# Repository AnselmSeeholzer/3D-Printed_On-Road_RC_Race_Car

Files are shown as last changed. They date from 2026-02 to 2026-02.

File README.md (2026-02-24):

# 3D-Printed On-Road RC Race Car

Videos can be found here:
[Video1](https://youtu.be/ogYVA5u91Qc?si=TGJ7EXKurzWOe1Sa)
[Video2](https://youtu.be/yxx4tnBufh8?si=RkOAHaVWVVsFRw-e)
[Video3](https://youtu.be/c6_NunxIvkY?si=fuwjfYf_-NPKvzkU)

With this 3d-printable RC-car I took part in the 2025 *Instructables Autodesk Make it Move Engeneering Student Contest* and the RC-car has won the *3D Printing Judge`s Price*.  

Detailed building instructions with a complete .f3z-file can be found on the [Instructables](https://www.instructables.com/3D-Printed-On-Road-RC-Race-Car/) website. The Instructable (without pictures and .f3z-file) was also transferred in this repository with printable .3mf-files.  

Some additional information about e.g. the suspension layout, BoM can be found in /some_information_about_the_rccar/
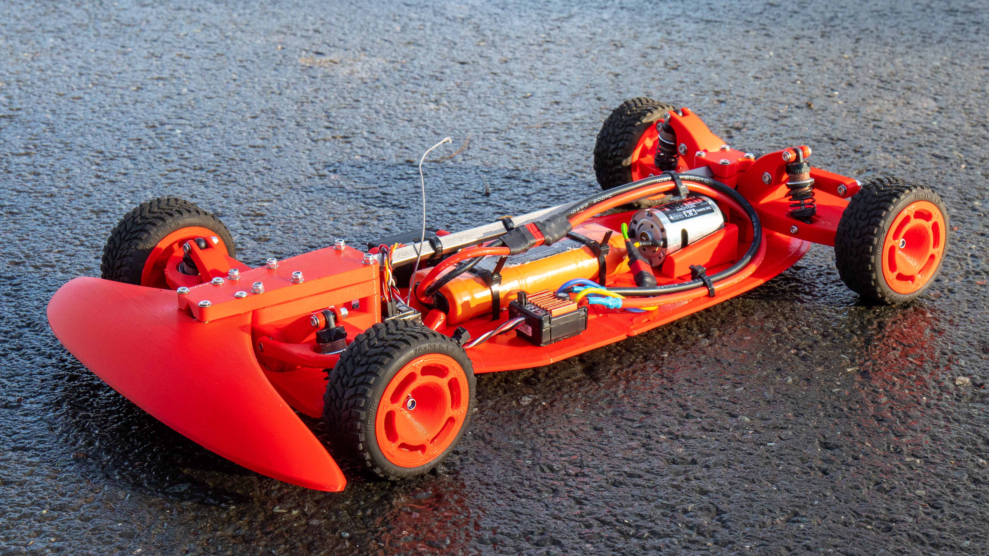
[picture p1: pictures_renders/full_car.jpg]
full_car_photo
  
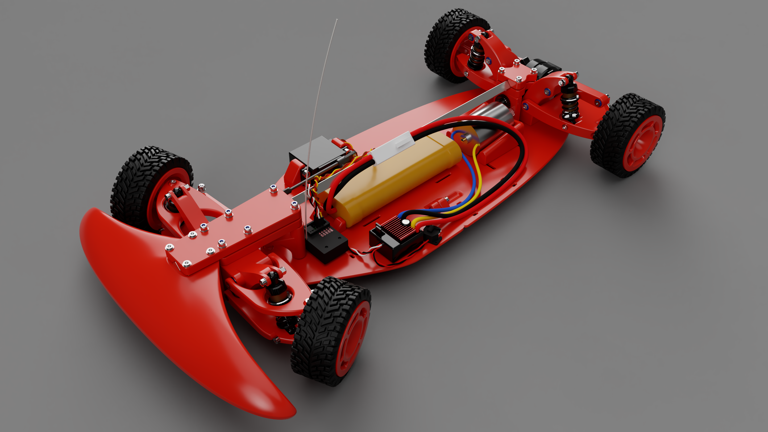
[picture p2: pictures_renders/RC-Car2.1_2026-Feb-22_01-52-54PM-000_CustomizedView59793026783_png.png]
full_car_render
  
full_car_render  
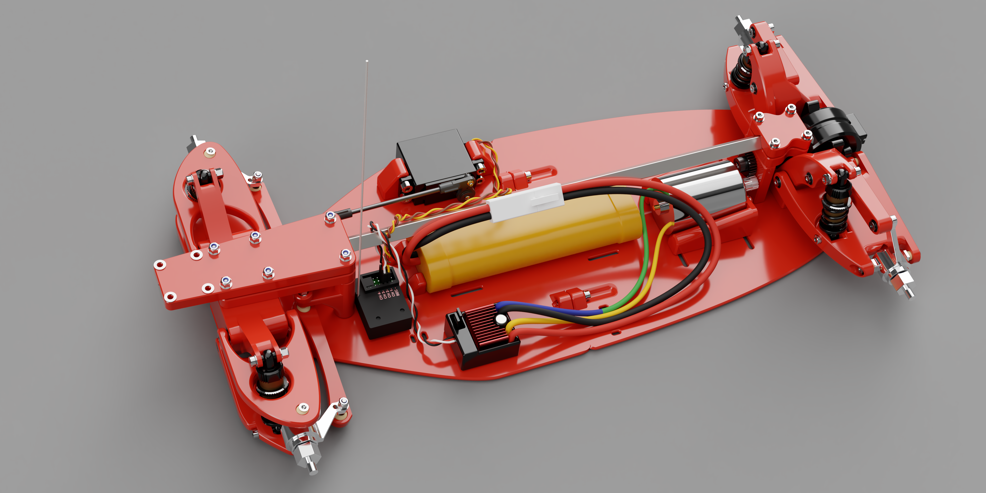
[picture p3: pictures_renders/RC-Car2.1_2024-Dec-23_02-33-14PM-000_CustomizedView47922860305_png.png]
full_car_render
  
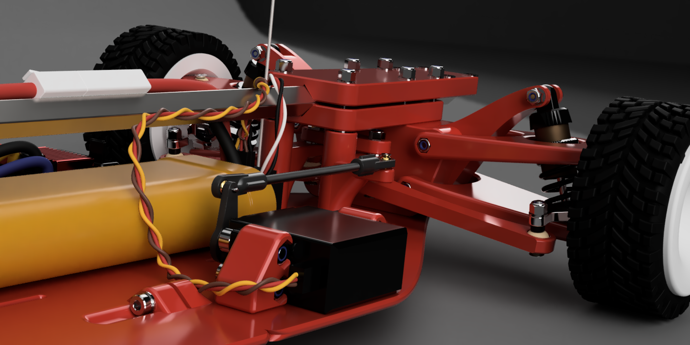
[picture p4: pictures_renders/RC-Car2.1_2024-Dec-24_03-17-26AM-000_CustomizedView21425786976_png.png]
full_car_render
  
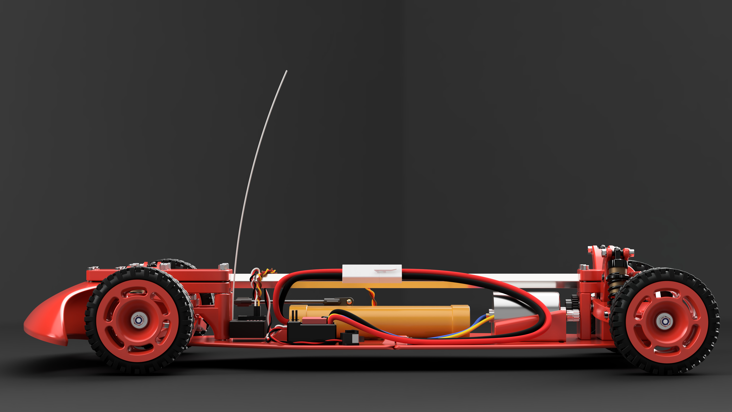
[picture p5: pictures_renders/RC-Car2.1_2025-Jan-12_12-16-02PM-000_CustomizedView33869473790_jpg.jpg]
full_car_render
  

---

## Introduction

This project showcases a 3D-printed RC race car that I designed and refined over the course of 18 months. As a physics student with a passion for vehicle dynamics, I wanted to combine my love for cars with hands-on learning. Inspired by YouTube creators like XF Motorsports, Indeterminate Design and the book Tune to Win by Carroll Smith, this project allowed me to explore the fascinating and complex field of vehicle dynamics.

The idea behind this project was not just to create an RC car, but to design one that reflects core principles of performance and handling. Through this process, I learned how concepts like weight distribution, suspension geometry, and grip dynamics work together to affect a vehicle's behavior. This Instructable is a step-by-step guide to building your own RC car, while also offering insights into the design decisions.

While designing and printing an RC car might seem challenging, I've optimized most parts to be straightforward to print -- even on a less-than-perfectly calibrated 3D printer. All holes for every bolt, nut, bearing and every tolerance are designed parametrically, so every feature's size can be easily adjusted to your likings in Autodesk Fusion. To determine if the parameters need to be changed, I have designed two test objects which use less than 10 g of filament to print.

---

## Project Goals

The main goals and conditions for this RC car were:

- **On-Road Focus**
  This car is purpose-built for smooth, on-road surfaces. Off-road capabilities were intentionally not prioritized.

- **Responsive and Predictable Handling**
  The car should feel intuitive and smooth to drive, allowing the driver to push it to its limits. Oversteer and understeer should be intentionally controllable, making it possible to explore the edge of grip and maintain a challenging driving experience.

- **Rear-Wheel Drive with Differential**
  A rear-wheel-drive setup was chosen for simplicity and driving fun. A differential ensures that the rear wheels rotate at different speeds during cornering, minimizing unwanted slip.

- **Optimized Weight Distribution**
  All heavy components are placed close to the car's center to reduce rotational inertia.

- **Efficient Suspension Design**
  The suspension is designed to maximize the contact area between the tires and the ground in all conditions (cornering, bumps, etc.), which increases grip. Internal friction at linkage points is minimized by using ball bearings or spherical bearings, enhancing the suspension's efficiency.

- **Ease of Maintenance**
  The car's design ensures that components are easily accessible for servicing and replacing parts.

---

## Why I Built This Project

I've always been fascinated by all kind of vehicles on wheels like stunt scooters, mountain bikes and more recently race cars. The physics involved in driving dynamics and car design offer a unique mix of theory and practical application. My interest deepened after watching DIY race car projects on YouTube and reading Tune to Win, which provides a great introduction to vehicle dynamics.

As a physics student, I already had a good understanding of basic physical concepts like force, torque, inertia and momentum. However, vehicle dynamics is a nuanced and complex field, and I wanted to expand my knowledge through hands-on experimentation. Designing this RC car from scratch was the perfect way to bridge theory and practice.

---

## Design Principles

The design process was guided by key engineering principles to ensure the car performs well on the track. Here are some highlights:

- **Suspension Geometry**
  The suspension layout takes into account critical factors like camber, bumpsteer, caster angle, and roll center position.

- **Ackermann Steering**
  The steering geometry approximates Ackermann principles, ensuring the wheels turn at the correct angles for smooth cornering.

- **Bump Steer Mitigation**
  The steering system is designed to minimize bump steer, which could cause unpredictable handling when the suspension compresses.

I measured different geometry layouts in Autodesk Fusion by using 2D sketches. This Data was put into spreadsheets to analyze the suspension geometry and simulate different scenarios (e.g., cornering, bumps). The tables and graphs of the final layout are attached to this Instructable for anyone interested in the technical details. For those who are interested I go into more detail of some design choices in the last chapter of this Instructable.

---

## Challenges and Lessons Learned

### 1. Learning About Vehicle Dynamics

Throughout this project, I learned a lot about vehicle dynamics. The car performs well and is fun to drive, as you can see in the videos. However, it's difficult to say which specific design choices contributed the most to its handling. What I can confidently say is that the combination of decisions led to a car that feels smooth and responsive.

That said, I'd love to have someone with more RC car experience -- either as a hobbyist or a professional -- test drive it. They could provide valuable feedback and a more objective comparison to other RC cars. My last time driving an RC car before this project was over 10 years ago, so my frame of reference is somewhat limited.

### 2. 3D Printing: My First Major Project

This RC car was my first major 3D printing project. Unsurprisingly, the first prototypes had plenty of beginner mistakes. I underestimated how much of a difference fine-tuning print settings like speed, acceleration, cooling, and flow rates could make. Early on, some parts didn't fit together as expected, which led me to explore slicer configurations and better understand how to achieve precise tolerances.

With each iteration, I refined both the design and the print quality. By the end, I had not only a functional RC car but also a much better understanding of 3D printing and prototyping.

### 3. Learning CAD with Autodesk Fusion

This project was also my first big CAD undertaking and only my second project in Autodesk Fusion. Having no prior CAD experience, I encountered a steep learning curve. Here are the main takeaways:

- **2D sketches for Suspension Layout:** Using 2D sketches to define the car's geometry and suspension layout helped me visualize and plan the relationships between components before moving on to 3D parts.
- **Evolving Design Skills:** As I gained more experience with Fusion 360, I discovered new tools and features. Consequently, parts designed later in the project were more refined compared to the earlier ones, which often felt clunky or inconsistent.
- **Ignoring Manufacturability:** Early on, I didn't consider the practical aspects of 3D printing or assembly. Some designs looked good in Fusion but turned out to be challenging to print or assemble.
- **No Parameters at First:** I initially didn't use parameters for dimensions because I didn't know about their existence. This meant I had to manually update dimensions across multiple parts when making changes. The repetitive adjustments were time-consuming and inefficient. Learning to use parameters was a game-changer for speeding up revisions and maintaining consistency.

Because of my steep learning curve in Autodesk Fusion and 3D printing, I decided to start the project with the same suspension geometry from scratch again and redesign every single part - and it was definitely worth it. The redesigned RC car features a cohesive look, with parts that are both easy to print and structurally robust. But still, I learned a lot this time too.

---

## Reflection

Looking back, this project wasn't just about building an RC car -- it was also an intensive learning experience in 3D printing, CAD design, and engineering principles. While there were plenty of mistakes along the way, each one was an opportunity to learn and improve.

---

## Supplies

### Tools

- 3d printer (I used Sovol SV07)
- approx. 500 g PLA
- approx. 400 g TPU/ tough PLA/ any impact resistant filament
- soldering iron
- soldering iron tips for setting brass inserts
- tools for your screws (I recommend Torx drive) and nuts
- some grease

### RC-specific hardware

- 4x HSP Wheel Axle 1/10 (part number 02033)
- 4x HSP Hub 1/10 with bearings (part number 02014)
- 2x HSP Dogbone 77 mm (part number 08060) (You need the Dogbone advertised as 77 mm length. Its distance between the center of the pins is actually 72 mm.)
- 1x HSP Differential (part number 02051) (The front version *with the long shaft* is needed. You can also use the rear version and simply buy a separate long shaft.)
- 4x 1/10 tires (approx. 70 -75 mm outer diameter) (You can also use standard HEX12 RC car rims instead of the 3d printed rims of this model)
- 4x shock absorbers 50 mm (I recommend getting a relatively good one with different springs (having the right spring rate is super important) and oil dampening. I use "Yeah Racing Big Bore Go".
- 1x transmitter/receiver combo, ESC and 540 motor. I use "Carlson Reflex X1", "Hobbywing 1060" and "Tamiya Torque Tuned".
- 1x gear for motor and differential each. The differential has an internal gearing of 1:3. Use a gearing compatible with your motors KV rating. I use a 21 teeth 48 dp motor gear and a 43 teeth 48 dp differential gear. So my total gearing is 1:6.143. The differential gear's diameter must be below 2 cm.

### General hardware

- M2 flat head screw:
  - 8 mm (any length between 8 and 12 mm) (1x)
- M2 brass insert (length 3mm) (1x)
- M3 flat head screws:
  - 6 mm (2x)
  - 8 mm (12x)
  - 12 mm (8x)
  - 14 mm (4x)
  - 16 mm (4x)
  - 20 mm (8x)
  - 22 mm (6x)
  - 25 mm (2x)
  - 30 mm (2x)
  - 45 mm (4x)
  - 60 mm (6x)
- M3 socket head screws:
  - 18 mm (2x)
  - 20 mm (2x)
- M3 ultra thin head
  - 8mm (4x)
- M3 brass insert (length 5.7 mm) (26x)
- M3 lock nut (18x)
- M3 square nut (2x)
- M3 washer (diameter 6.7 mm) (25x)
- M4 socket head screw
  - 16mm (4x)
- M4 lock nut (8x)
- M4 washer (diameter under 12 mm) (4x)
- Bearing 693 (x18)
- Bearing MR105 (1x)

---

## Step 1: General Print Settings and Assembly Tips

Because we want our parts to be strong, a few print settings are very important.

To achieve a good adhesion between the layers, I print most parts without the use of my part cooling fan. Only when bridging occurs, I set it to 100%. Additionally, printing at a low constant flow rate has shown very good results in my experience. Furthermore over extruding the print a small amount has also shown to improve layer adhesion by filling in small voids that occur between layer lines. Regarding temperatures, I printed in the higher end of the manufacturers recommendation. In a video of CNC Kitchen on YouTube, "Transparent FDM Prints are Clearly Stronger!", the reasons behind this are explained perfectly. I print at slow 3 mm3/s on a 0.6 mm nozzle with a 0.3 mm layer height, but consistently achieve good results this way. Furthermore I use a random seam positioning, in order to avoid having weakspots on a continuous seam, but more importantly, bearings are really concentric in their holes and do not get pushed to one side, because of an aligned seam.

You also have to print some cylindrical spacers. Because of their small size, their diameter us usually smaller than intended to after printing. If that's the case with your printer, you can scale the spacers in the x-y-plane up in your slicer. I found it helpful for the assembly process, when the M3 screws tap a small thread in the spacers, so they don't fall off the screw while assembling.

All parts are printed with PLA if not stated else.

For reference, I attached a file with the material and mass of each part (not including any hardware) I printed.

A small safety precaution: wear protective glasses when removing supports.

*Attachment: material_and_mass_of_each_part.pdf*

---

## Step 2: Test Object 1

It may be a bit boring to start this way, but this print ensures that all prints happening afterwards will come out well calibrated according to your printer.

The first print is "TestObject1". Slice it with the settings you are going to use with the rest of the parts and print it. Check if all the hardware fits in the holes as shown in the pictures. The bearings should have a tight fit.

If everything works, you can move on to "Step3: Test Object 2".

If something does not fit, the according parameter has to be adjusted in Autodesk Fusion (the parameters marked as favorites), the "TestObject1" has to be exported from Autodesk Fusion and sliced and printed again. If everything fits now, you can move on to "Step3: Test object 2", if not, you have to readjust and reprint the test object.

In the Fusion project exist three errors related to changing the parameters I wasn't able to solve. They do cause any issues with the model.

---

## Step 3: Test Object 2

The "TestObject2" determines the tolerance needed for printing a spherical joint used in the front wishbones and steer rods.

Printing this spherical joint as a print-in-place object is the most advanced print of this project. The sphere has to be printed "in air" without adhering much to its frame underneath or to the sides because of the placement of seams. If the sphere bonds too much to its frame, it can't be broken free and can't move.

Having a smaller height helps a lot. So you have to set your layer height to a maximum of 0.15 mm.

To print this object in the best way, we have to place the seams in the right spots and manually edit a few .gcode lines.

In your slicer, use paint-on-seams to place the seams as shown in the pictures 4 and 5. The blue lines represent where the seams are set. The seams shouldn't be touching the walls next to each other from the sphere and the frame.

After exporting the .gcode search in your slicer-preview for the .gcode-command that starts printing the sphere (picture 6). At this point in the print, the part cooling fan should be running at 100 %. But because I print everything else with the part cooling fan at 0 %, it needs to accelerate to that 100% rpm first and this takes 1 to 2 seconds. So when the 100 % part cooling is actually needed, I get an fan than is in the 0 to 20 % rpm range. That causes the sphere to bond to its frame.

To tackle this problem, I basically moved the command for the fan to go to 100 % up a few lines, so it definitely is at 100% rpm, when I need it to be.

You have write down the .gcode-line that starts printing the sphere. After that, open up the .gcode-file using a text editor like Notepad++ and search for that exact .gcode-line (picture 7). One occurrence should pop up (that's exactly where your sphere starts printing). Above the given .gcode-line should be the command "M106 255" and/or "SET_FAN_SPEED FAN=extruder_partfan SPEED=1". Those commands set the part cooling fan speed to 100 %. Simply copy that command, and insert it a few lines above (picture 8). This way the fan starts accelerating earlier. Save the file, and you are good to print.

After printing, check if a M3 screw can fit the hole. I prefer slightly tighter tolerances for these holes to ensure a precise concentric fit. If it doesn't fit, adjust the parameter "PrintInPlaceBallJointHoleDia" in Autodesk Fusion in the same way as described in "Step2: Test Object 1". Following up, gently try to break the sphere free from its cage, using a HEX drive. (Wear protective glasses! If the sphere adheres too much to its cage and you break the part, something can fly towards your eyes.)

If the sphere adheres too much to the cage or if it even feels too loose, adjust the parameter "PrintInPlaceBallJointTolerance" in Autodesk Fusion in the same way as described in "Step2: Test Object 1" and export the model. Don't forget that you unfortunately have to redo the seam painting and g.code-editing. (Having a post-processing-script that automatically moves the fan command is something I'm planning to do in the future.) Reprint it and check the tolerances again.

If the parameters finally fit your printer, you can move on to the next step.

---

## Step 4: The Front Lower Wishbones

While being in the work flow for editing .gcode, we start with the only three parts of this project that need this kind of attention, the front wishbones and steer rods. We start by printing the lower wishbone.

We again have to...

- ensure the layer height is not greater than 0.15 mm where the sphere prints,
- paint the paint-on-seams the way we did in the test print,
- manually move the fan command in the .gcode the way we did in the test print.

After printing the part, the support structures must be removed by using pliers and a small hex drive (pictures 5-8). Gently try to break the sphere free from its cage, using a HEX drive (pictures 9 and 10). Mount the shock by using a M3 square nut and a M3 socket head 20 mm screw (pictures 11 and 12).

After successfully assembling one front lower wishbone, repeat the process again, as the right and left versions of this part are identical. Only the shock has to be mounted the other way.

---

## Step 5: The Front Upper Wishbones

The process is identical to the one from the step before. We again have to...

- ensure the layer height is not greater than 0.15 mm where the sphere prints,
- paint the paint-on-seams the way we did in the test print,
- manually move the fan command in the .gcode the way we did in the test print.

After printing the part, the support structures must be removed by using pliers. Gently try to break the sphere free from its cage, using a HEX drive.

Mirror the part in your slicer and repeat the process again, as the right and left versions of this part are not identical but symmetrical. Mirroring the part in your slicer saves you time (compared to slicing the right and left part separately), because you don't have to do the seam painting again.

---

## Step 6: The Steer Rods

This is the last part, where .gcode editing is needed.

Again, the process the same as before just with two (!) spherical joints per part. We have to...

- ensure the layer height is not greater than 0.15 mm where the sphere prints,
- paint the paint-on-seams the way we did in the test print,
- manually move the fan command in the .gcode the way we did in the test print.

After printing the part, gently try to break the sphere free from its cage, using a HEX drive.

Simply print this part twice, as the left and right versions are identical.

---

## Step 7: The Front Base

The next part to be printed is the FrontBase.

You have to use some supports when printing it. I recommend using tree supports. Remove them by using pliers.

Use a relatively long M3 screw, a M3 nut and washers (I only use a washer on one side in this example, but it is better to use one on each side) to press the 693 bearings in place without forgetting the bearing spacer, which needs to be inserted between both bearings for smooth operation.

Repeat the process for the other bearings.

---

## Step 8: The Assembly of the Front End 1 (Wishbones)

In this step, all the parts we have printed until now get assembled together, beginning to build the front end of the car.

Start by inserting a M3 lock nut into the front lower wishbone. Mount the front lower wishbone to the front base by using a M3 flat head screw (45 mm). Ensure that you choose the right side by checking if the mounting points for the shock are aligned. Following up, insert a M3 lock nut in the front upper wishbone and mount it to the front base by using a M3 flat head screw (45 mm). Next, mount the shock to the front base with a M3 flat head screw (20 mm), two M3 washers and a M3 lock nut.

Ensure that the upper wishbone does not collide with the shock when being moved. If that's the case you have mounted the wrong upper wishbone to this side and have to replace with the other one.

Repeat the process in the same way for the other side.

Apply some grease to the spherical bearings.

---

## Step 9: The Steer Lever and Coupler

Print the right and left steer lever, remove the support material and press the 693 bearings with the bearing spacers into their holes by using the same technique as before.

After printing the steer lever coupler, press the 693 bearings into the holes. The 693 bearings needs a very tight fit on this part. Printing it with a slightly higher flower rate results in a smaller inner diameter of the hole, which ensures a tight fit.

---

## Step 10: The Assembly of the Front End 2 (Steering)

We continue assembling the front end. Insert a M3 flat head screw ( 20 mm) into the steer rod and the steer lever (oriented as in the pictures), put a M3 washer on top of the steer lever, put the steer coupler on top of that (with the bearing facing the washer) and secure everything with a M3 lock nut mounted upside down.

Repeat the process for the other steer rod and steer lever. Check for the right orientation of everything.

Mount your hubs with the included bearings and axles to the wishbones by using M3 flat head screws (14 mm). You might have to add a small chamfer to the hubs mounting point in order to avoid collisions with the wishbones. Between the left and right hub exists a small difference, as they are only symmetrical to each other, not identical. Ensure that the hub's mounting arm for the steer rod is in the orientation closer to the ground.

Next, mount the steer rods to the hubs in the hole shown in the pictures. Do that by using a M3 flat head screw (20 mm), a M3 washer and a M3 lock nut.

Insert a M2 brass insert into the right steer arm. Here is a tutorial for inserting threaded brass inserts.

---

## Step 11: Printing and Attaching the Front Bottom Plate and Top Rod Connection

Start by printing the front base and the front top rod connection. The parts need no support. Print the front top rod connection parts very strong. I printed my parts 100 % solid. In this step, only the bottom part of the front top rod connection mounted to the front end. The top part of the front top rod connection is needed in a later step.

Insert two M3 brass inserts into the front bottom plate.

Mount the front end to the front bottom plate by using six M3 flat head screws (60 mm) and 4 M3 washers. The M3 washer sit below and above the steer levers. Attach the front top rod connection bottom part to the same six M3 flat head screws.

---

## Step 12: The Rear Lower Wishbones

This part transmits a lot of power from the hub to the rear base. The part will break when using PLA. TPU holds up perfectly. No TPU part broke during testing. This time, I tried tough PLA by Material4Print, which has a greater impact resistance than "normal" PLA because of additives. The tough PLA gives some more rigidity than the TPU I used before. The tough PLA has worked well in the first tests, but I haven't tested it as long as the TPU version. Besides using an impact resistant material, printing this part with 6 or more walls is recommended.

After printing, remove the support structures of the lower wishbone after printing it.

Press a 693 bearing in each of the four holes.

Mount the shock to the lower wishbone by using a M3 socket head screw (18 mm) and a M3 square nut.

Attach your rear hub to the lower wishbone with two M3 flat head screws (12 mm) and the printed spacers. - While taking the pictures for this Instructable, I did something wrong. I mounted the left hub to the right lower wishbone. You can spot the "error" in the area of the yellow circle in two pictures. The hubs mounting arm should be "closer" to the shock. I only noticed this later and exchanged the two hubs. The last picture in this step shows the right orientation for the hub when fully assembled.

Mirror the part in your slicer and repeat the process for the other side.

---

## Step 13: The Rear Upper Wishbones

After printing the rear upper wishbone, press two 693 bearings with their bearing spacer into their holes by using the same technique as before. Insert and M3 lock nut into its position.

Repeat the process again, as the right and left versions of this part are identical.

---

## Step 14: The Rear Base

Print the rear base with tree supports and remove them with pliers.

Press two 693 bearings with their spacers in each the left and right side.

Insert the eight M3 brass inserts into their holes by using a soldering iron.

Loosely place the differential into the rear base. Ensure that it is greased and moving freely.

---

## Step 15: The Assembly of the Rear End

Attach the two spacers with two M3 flat head screws (14 mm) to the rear lower wishbone (pictures 1 and 2).

Slide the dogbone into through the rear lower wishbone into the hub (pictures 3 and 4).

Mount the M3 flat head screws to the rear base an ensure that the dogbone is in the differential and the hub (pictures 5 and 6).

By using a M3 flat head screw, two M3 washers and a M3 lock nut, attach the shock to the rear base (pictures 7 and 8).

Mount the rear upper wishbone to the rear base by using a M3 flat head screw (30 mm) (pictures 9 and 10).

Attach the rear upper wishbone to the hubs upper mounting point (which has a M3 thread) by using a M3 flat head screw (20 mm) and the spacer (pictures 11 and 12). Add a M3 washer and a M3 lock nut, which acts as a counter nut to the hub's mounting point's thread (picture 13).

Repeat the process for the other side (pictures 14 and 15).

---

## Step 16: Attaching the Rear End to the Rear Bottom Plate

Print the rear bottom plate. Mount the rear end to the rear bottom plate by using M3 flat head screws (four 20 mm, four 8 mm). Use the 8 mm screws first as shown in picture 4, then use the 20 mm screws as shown in picture 5.

Print the differential shaft support bracket and press in a MR 105 bearing and insert four M3 brass inserts with a soldering iron. Slide it onto the differential shaft and mount it to the rear bottom plate with two M3 flat head screws (8 mm) as shown in picture 12.

---

## Step 17: Connecting the Rear and Front Bottom Plate

Connect the rear and front bottom plate by using two M3 socket head screws (20 mm) and two M3 washers.

---

## Step 18: Attaching the Steering Servo

Print the two servo mounting brackets and insert two M3 brass inserts into each one (picture 3).

Mount the servo mounting brackets to the servo (pictures 4 and 5).

Attach the servo and its servo mounting brackets to the front bottom plate by using four M3 flat head screws (8 mm)(picture 6).

Connect the servo arm to the right steer lever by using a M3 rod with a spherical joint on each end (pictures 7 and 8). The distance between the center points of the spherical joints is 9.5 cm for a optimal steering behavior. If the distance is off, the right and left steering ratios are slightly different.

---

## Step 19: Attaching the Top Rod

After printing the read top rod connection (picture 2), attach the metal square profile (8x8 mm, 40.4 cm) to the rear end by using the rear top rod connection, four M3 flat head bolts ( mm) and four M3 washers (pictures 1 and 3).

Attach the metal square profile to the front end by using the front top connection, six M3 lock nuts and six M3 washers.

To ensure a good alignment...

- do this mounting process while the bottom plate is standing on a very flat surface. This way, you will notice, when the front or rear end aren't sitting on one plane.
- Screw in every bolt and nut only a small distance at a time. This way you correct a misalignment in small increments.

When you have finished attaching the top rod, you'll notice how the whole structure, which was very flexible before, gained an extreme amount of stiffness. The exact reason for that is explained at the end of this Instructable.

---

## Step 20: Attaching the Motor

Start by mounting the differential gear on the differential's shaft (pictures 1 and 2). I used a 48 dp 43 t gear. Definitely use some screw locking adhesive here.

Print the motor mounting bracket (picture 3) with a heat resistant material like PETG or in my case tough PLA and insert four M3 brass inserts (picture 4). Attach the motor to the motor mounting bracket with two M3 flat head screws (6 mm) (pictures 5 and 6).

Mount the motor with its mounting bracket to the rear bottom plate by using four M3 ultra thin head screws (8 mm) (pictures 7, 8 and 10).

Attach the motor gear to the motor so that it meshes nicely with the differential gear and set the right distance between them (pictures 9 and 10). Here is a tutorial for setting the distance right. Grease the gears.

---

## Step 21: Electronics

In this step, wire up all your electric components and hold them in place by using zip ties in the according slots and thick double sided adhesive strips. Always refer to your manufacturers manual when wiring up electric components. Here is a tutorial for basic RC electronics and a tutorial for soldering RC connectors.

If you need to solder components, always work in a well ventilated area and minimize exposure to the fumes.

---

## Step 22: Attaching the Wheels

Print the rim by using tree supports and remove them with pliers (pictures 1-4). Put the tire onto the rim (picture 5). Insert the HEX12 nut, which is part of the hub assembly, with a tight fit by pressing it into its according hole with a M4 screw, washer and nut (pictures 6 and 7).

Repeat this process four times.

Attach two assembled wheels (picture 8) with each a M4 lock nut and M4 washer and without the pin in the hub's axle, which is intended for power transmission, to the front end's hubs (picture 9) by using a 7 mm socket wrench and a 2.5 mm allen key (picture 10). We don't need power transmission in the front and are able to fine tune the bearing preload this way.

Attach the other two assembled wheels to the rear end's hubs the same way, but with the pin in the hub's axle for power transmission installed (pictures 11 and 12). My pin broke after a few months of testing, so i replaced it with a M2 threaded rod, which fits perfectly.

---

## Step 23: Attaching the Front Bumper

The last part to attach is the front bumper.

I recommend using an impact resistant material, but PLA also showed some really good results in saving the car in a crash, if printed with a high wall thickness.

Insert four M3 brass inserts and attach the front bumper to the top rod.

You are ready to go!!

---

## Step 24: Geometry and Suspension Design

When designing this RC car, I decided to aim for a scale of approximately 1:10. This size offered a balance between sufficient space for components and a manageable overall build. I started with the purchase of a rear differential, dogbone-style drive shafts, and wheel hubs, which established the rear track width (22.3 cm). For the front track width, I opted for a slightly wider dimension (23.5 cm) to improve stability and traction during cornering.

The ratio of track width to wheelbase was another key consideration. Based on comparisons with real-world designs and other RC cars, I chose a 1:1.6 ratio, which resulted in a wheelbase of 36.6 cm. This configuration was chosen to promote stable and predictable handling, particularly during high-speed cornering.

The suspension travel was set to approximately 15-20 mm, which includes both compression and rebound. This allows the wheels to compress around 20-25% of their diameter. Given the relatively rough texture of asphalt for small-scale vehicles, this suspension travel is needed.

To maximize grip, I designed the suspension geometry to maintain a near-linear increase in camber as the suspension compresses. This ensures a consistent contact patch during dynamic conditions, such as cornering or bumps. The roll center was positioned low and remains stable across scenarios, contributing to the car's predictable handling. Additionally, I implemented a caster angle of 10 degrees, which adds dynamic camber during cornering when it's most needed.

Bump steer, an issue where suspension travel unintentionally alters the steering angle, was minimized through careful adjustments. The steering system approximates Ackermann geometry but includes modifications to account for lateral weight transfer. The outer wheel, benefiting from increased grip during cornering, is set to turn more sharply than the inner wheel, optimizing cornering performance.

Anti-dive geometry was not included, as the lack of braking components made it unnecessary and would have added complexity without significant benefits.

As I already pointed out, I'm nowhere near of being a suspension geometry expert, so keep that in mind. For those interested in learning more about suspension geometries, I highly recommend this introductory video by XF Motorsports.

*Attachments: Front Suspension.pdf, Rear Suspension.pdf*

---

## Step 25: Strength and Stiffness

Picture 1: When the car is moving on its wheels, it compensate its own gravitational force and additional loads induced by driving dynamics. When assuming all those forces, Fload, attack in the center of gravity, two opposing torques, M1 and M2 are created at the front and rear end of the car. Through does opposing torque, the top rod is experiencing compression forces while the bottom plate is experiencing tensile forces. The metal top rod is very resistant against buckling while the bottom plate made out of PLA has a high tensile modulus and strength. In consequence, the system is very rigid.

Picture 2: If the car drives over a bump on only the left or the right side, opposing torques are induced at the front and rear end. The square profile top rod contributes most to the resistance against such torsional forces. Although a square profile has less resistance against torsional forces than a cylindrical profile, it is much easier to clamp with the top rod connection at the front and back of the car. Having a cylindrical top rod resulted in much more torsional deflection because the round bar was able to rotate slightly in the top rod connection. Having a square profile, the car can only experience as much torsional deflection as the top rod, which is almost negligible with a 8x8 mm titanium square profile (or aluminum or steel).

Furthermore in case of a frontal crash, the impact gets distributed from the front bumper through the top rod to the whole car, which reduces impact spikes in a single part.

---

## Step 26: More Test Videos

https://youtu.be/c6_NunxIvkY?si=WqnR-BRy5YHN8YEP
https://youtu.be/yxx4tnBufh8?si=RkOAHaVWVVsFRw-e  
https://youtu.be/c6_NunxIvkY?si=fuwjfYf_-NPKvzkU

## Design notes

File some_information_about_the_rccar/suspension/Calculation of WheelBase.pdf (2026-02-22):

# Calculation of Wheelbase

Targeted Ratio: TrackWidth : WheelBase = 1 : 1,6

RearTrackWidth [cm]: | 22.3
According Wheelbase [cm]: | 35.68
FrontTrackWidth [cm]: | 23.5
According Wheelbase [cm]: | 37.6
Average Wheelbase [cm]: | 36.64

## Estimated Values for Comparison

Type | Ratio TrackWidth : WheelBase
On-Road-RC Tamiya TT-02 F1 NASCAR Cup Series IndyCar LMP1 (Le Mans Prototypes) LMP2 (Le Mans Prototypes) GT4 GT3 Group A Rallyecars Group B Rallyecars DTM Rallyecars FSAE | approx. 1,4 - 1,8 approx. 1,4 approx. 1,8 - 2,2 approx. 1,8 - 2,2 approx. 1,8 - 2,2 approx. 1,6 - 1,9 approx. 1,6 - 1,9 approx. 1,6 - 1,8 approx. 1,6 - 1,8 approx. 1,4 - 1,7 approx. 1,3 - 1,6 approx. 1,4 - 1,7 approx. 1,4 - 1,6 approx. 1,3 - 1,7

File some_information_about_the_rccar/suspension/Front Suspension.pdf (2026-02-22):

# FrontSusLayout1

# TrackWidth 23,5cm

# Camber and WheelTravel

Travel measured from center of tirepatch.

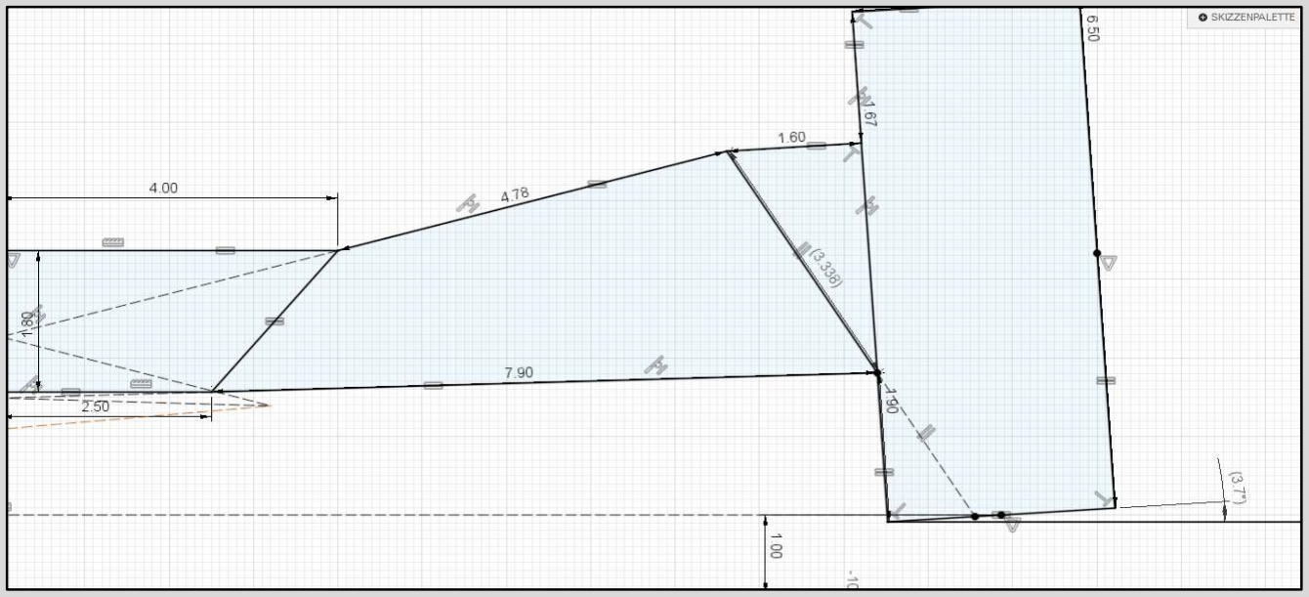
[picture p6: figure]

Travel [mm] | Camber [°]
-10 -9 -8 -7 -6 -5 -4 -3 -2 -1 0 -0.3 1 -0.6 2 -0.9 3 -1.2 4 -1.6 5 -1.9 6 -2.2 7 -2.6 8 -3 9 -3.3 10 -3.7 11 -4.1 12 -4.5 13 -4.9 14 -5.3 15 -5.7 16 -6.1 17 -6.5 18 -7 19 -7.4 20 -7.8 21 -8.3 22 -8.7 23 -9.2 24 -9.7 25 -10.2 | 2.5 2.2 2 1.7 1.5 1.2 0.9 0.6 0.4 0.1

# RollCenter

# RollCenter with equal L/R-Travel

Travel [mm] | RollCenterHeigth above Ground [mm]
-10 -9 -8 -7 -6 | 31.7 30.7 29.7 28.6 27.6
-5 -4 -3 -2 -1 | 26.5 25.5 24.4 23.4 22.4

0 21.3
1 20.3 2 19.2 3 18.2 4 17.2 5 16.1

6 15.1 7 14 8 13 9 12 10 10.9

11 9.9 12 8.9 13 7.8 14 6.8 15 5.8 16 4.7 17 3.7 18 2.7 19 1.6 20 0.6

21 -0.4 22 -1.4 23 -2.5 24 -3.5 25 -4.5

# RollCenter with opposite, "equal" L/R-Travel

(RollCenter travels to left in right-handed turns)
Travel [mm] | RollCenterHeigth above Ground [mm] | RollCenterTravel L/R [mm]
1 2 3 4 5 | 21.3 21.3 21.3 21.3 21.3 | 0.1 0.1 0.1 0.2 0.2 0.3 0.3 0.3 0.4 0.4
6 7 8 9 10 | 21.3 21.4 21.4 21.4 21.4

# RollCenter with LTravel = -2*RTravel

(RollCenter travels to left in right-handed turns)
Travel [mm] | RollCenterHeigth above Ground [mm] | RollCenterTravel L/R [mm]
0 | 21.3 | 0
2 4 6 8 10 | 20.8 20.3 19.8 19.3 18.8 | 0.1 0.2 0.3 0.4 0.5
12 14 16 18 20 | 18.3 17.8 17.3 16.8 16.3 | 0.7 0.8 1 1.1 1.3

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
-10 -9 -8 -7 -6 -5 -4 -3 -2 -1 | 0 | 1 | 2 | 3 | 4 | 5 | 6 | 7 | 8 | 9 10 11 12 13 14 15 16 17 18 19 20 21 22 23 24 25 Camber and WheelTravel Camber [°]

## WheelTravel [mm]

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
-10 | -9 | -8 | -7 | -6 | -5 | -4 | -3 | -2 | -1 | 0 | 1 | 2 | 3 | 4 | 5 | 6 | 7 | 8 | 9 | 10 | 11 | 12 | 13 | 14 | 15 | 16 | 17 | 18 | 19 | 20 | 21 | 22 | 23 | 24 | 25

# RollCenterHeigth and equal L-/R-WheelTravel RollCenterHeigth

## above Ground [mm]

## WheelTravel [mm]

0

5

10

15

20

25

1 | 2 | 3 | 4 | 5 | 6 | 7 | 8 | 9 | 10 RollCenter with opposite, "equal" L/R-Travel

RollCenterHeight (above ground)

RollCenter-L/R-Travel (travels to the left in right-handed turns, vice versa) WheelTravel [mm] RC-Height [mm] RC-L/R [mm]

0

5

10

15

20

25

0 | 2 | 4 | 6 | 8 | 10 | 12 | 14 | 16 | 18 | 20 RollCenter with LTravel = -2*RTravel

RollCenterHeight (above ground)

RollCenter-L/R-Travel (travels to the left in right-handed turns, vice versa) WheelTravel [mm] RC-Height [mm] RC-L/R [mm]

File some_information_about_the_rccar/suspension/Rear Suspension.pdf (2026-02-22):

# RearSusLayout1

# TrackWidth 22,3cm

# Camber and WheelTravel

Travel measured from center of tirepatch.

Travel [mm] | Camber [°]
-10 -9 -8 -7 -6 -5 -4 -3 -2 -1 0 -0.2 1 -0.5 2 -0.8 3 -1.1 4 -1.4 5 -1.8 6 -2.1 7 -2.4 8 -2.7 9 -3.1 10 -3.4 11 -3.8 12 -4.1 13 -4.5 14 -4.9 15 -5.3 16 -5.6 17 -6 18 -6.4 19 -6.8 20 -7.2 21 -7.6 22 -8 23 -8.4 24 -8.9 25 -9.3 | 2.5 2.2 2 1.7 1.5 1.2 0.9 0.7 0.4 0.1

# RollCenter

## RollCenter with equal L/R-Travel

Travel [mm] | RollCenterHeigth above Ground [mm]
-10 -9 -8 -7 -6 | 26.7 25.8 24.9 24 23.1
-5 -4 -3 -2 -1 | 22.2 21.2 20.3 19.4 18.5

0 17.6
1 16.7 2 15.8 3 14.9 4 14 5 13.1

6 12.2 7 11.3 8 10.4 9 9.5 10 8.5

11 7.6 12 6.7 13 5.8 14 4.9 15 4 16 3.1 17 2.2 18 1.3 19 0.4 20 -0.5

21 -1.4 22 -2.3 23 -3.2 24 -4.1 25 -5

## RollCenter with opposite, "equal" L/R-Travel

(RollCenter travels to left in right-handed turns)
Travel [mm] | RollCenterHeigth above Ground [mm] | RollCenterTravel L/R [mm]
1 2 3 4 5 | 17.6 17.6 17.6 17.6 17.6 | 0.7 1.5 2.2 3 3.7 4.4 5.2 5.9 6.6 7.4
6 7 8 9 10 | 17.6 17.6 17.7 17.7 17.7

## RollCenter with LTravel = -2*RTravel

(RollCenter travels to left in right-handed turns)
Travel [mm] | RollCenterHeigth above Ground [mm] | RollCenterTravel L/R [mm]
0 | 17.6 | 0
2 4 6 8 10 | 17.2 16.7 16.3 15.8 15.4 | 1.1 2.3 3.6 4.9 6.3
12 14 16 18 20 | 14.9 14.5 14 13.6 13.1 | 7.7 9.2 10.8 12.5 14.3

# Travel measured from center of tirepatch

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
-10 -9 -8 -7 -6 -5 -4 -3 -2 -1 | 0 | 1 | 2 | 3 | 4 | 5 | 6 | 7 | 8 | 9 10 11 12 13 14 15 16 17 18 19 20 21 22 23 24 25 Camber and WheelTravel Camber [°] | WheelTravel [mm]

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
-10 | -9 | -8 | -7 | -6 | -5 | -4 | -3 | -2 | -1 | 0 | 1 | 2 | 3 | 4 | 5 | 6 | 7 | 8 | 9 | 10 | 11 | 12 | 13 | 14 | 15 | 16 | 17 | 18 | 19 | 20 | 21 | 22 | 23 | 24 | 25

# RollCenterHeigth and equal L-/R-WheelTravel RollCenterHeigth

## above Ground [mm]

## WheelTravel [mm]

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
1 | 2 | 3 | 4 | 5 | 6 | 7 | 8 | 9 | 10 RollCenter with opposite, "equal" L/R-Travel

RollCenterHeight (above ground)

RollCenter-L/R-Travel (travels to the left in right-handed turns, vice versa) WheelTravel [mm] RC-Height [mm] RC-L/R [mm]

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
0 | 2 | 4 | 6 | 8 | 10 | 12 | 14 | 16 | 18 | 20 RollCenter with LTravel = -2*RTravel

RollCenterHeight (above ground)

RollCenter-L/R-Travel (travels to the left in right-handed turns, vice versa) WheelTravel [mm] RC-Height [mm] RC-L/R [mm]

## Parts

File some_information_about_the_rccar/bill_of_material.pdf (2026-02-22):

# RC-specific components

Part name | Part number (without "_") | Part count
HSP wheel axle 1/10 | _02033 | 4
HSP Hub 1/10 | _02014 | 4
HSP Differential | _02051 | 1
HSP Dogbone 77 mm | _08060 | 2
Tires 1/10 | - | 4
Rims HEX12 1/10 | - | 4
Shock Absorber 50mm | - | 4
Transmitter/receiver combo | - | 1
ESC | - | 1
Motor | - | 1
Motor gear | - | 1
Differential gear | - | 1

Comment

Use the front version. Or use the rear version with an additional longer shaft. It is sold as 77 mm, but the bore-to-bore measurement is about 72 mm. Outer Diameter approx. 70 - 75 mm.
Optional, if you dont want to print rims.
One with several different springs and oil dampening is recommended. I use Carson Reflex X1.
I use Hobbywing 1060.
I use Tamiya Torque Tuned.
I use 48 dp 21 t.
I use 48 dp 43 t. MAX DIAMATER 2 cm.

## Screws, Nuts, Inserts

Part name | length [mm] | partCount | comment
M2 Flat Head | 8 | 1 Everything between 8 and 14 mm works.
M2 Brass Insert | - | | 1 Depth: 3 mm.
M3 Flat Head | 6 | 2
8 | 12
12 | 8
14 | 4
16 | 4
20 | 8
22 | 6
25 | 2
30 | 2
45 | 4
60 | 6
M3 Socket Head | 18 | 2
20 | 2
M3 Ultra Thin Head | 8 | 4 Everything between 8 and 10 mm works.
M3 Brass Insert | - | 26 Depth: 5.7 mm .
M3 Lock Nut | - | 18
M3 Square Nut | 2
M3 Washer | 25 "Best looking" diameter: 6.7 mm.
M4 Socket Head | 16 | 4
M4 Lock Nut | - | 8
M4 Washer | - | | 4 Diameter must be smaller than 12 mm.

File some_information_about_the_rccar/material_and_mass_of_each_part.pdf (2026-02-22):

Table is for all 3D-printed parts and for aftermarket parts (as differential, motor, ESC, hub, …), …
… not including standard hardware (as bolts, nuts, bearings, inserts, washers, ...) or nescessary support material.
RC-Car 1.0 | SUM (all 3Dprinted) = | 814.79 g
| Sum (PLA) = | 453.77 g
| Sum (toughPLA) = 361.02 g
PartName | Mass [g] (one part) | Mass*partcount [g] | Material
RearEnd | SUM (3Dprinted) = 212.31
RearBase LowerWB UpperWb DifferentialShaftSupportBracket BottomTopRodConnection TopTopRodConnection MotorBracket | 94.41 34.78 4.935 7.02 5.72 5.72 20.01 | 94.41 69.56 9.87 7.02 5.72 5.72 20.01 | ToughPLA (Material4Print) ToughPLA (Material4Print) ToughPLA (Material4Print) PLA (Material4Print) PLA (Material4Print) PLA (Material4Print) ToughPLA (Material4Print)
FrontEnd | SUM (3Dprinted) = | 153.3
LeftSteerLever | 5.13 | 5.13 | PLA (Material4Print)
RightSteerLever | 6.51 | 6.51 | PLA (Material4Print)
SteerLeverCuppler | 1.71 | 1.71 | PLA (Material4Print)
FrontBase | 52.47 | 52.47 | PLA (Material4Print)
FrontBaseSpacer | 0.4025 | 1.61 | PLA (Material4Print)
BottomTopRodConnection | 17.85 | 17.85 | PLA (Material4Print)
TopTopRodConnection | 23.92 | 23.92 | PLA (Material4Print)
LowerWB | 10.54 | 21.08 | PLA (Material4Print)
UpperWB | 8.28 | 16.56 | PLA (Material4Print)
MountingBrackets (Servo) | 3.23 | 6.46 | PLA (Material4Print)
BottomPlate | SUM (3Dprinted) = | 187.6
BackPlate FrontPlate | 99.64 87.96 | 99.64 87.96 | PLA (Material4Print) PLA (Material4Print)
FrontBumper | 108.34 | 108.34 | ToughPLA (Material4Print)
Rims | 38.31 | 153.24 | ToughPLA (Material4Print)

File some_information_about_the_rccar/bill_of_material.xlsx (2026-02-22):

RC-specific components |  |  |  | Screws, Nuts, Inserts
Part name | Part number (without "_") | Part count | Comment | Part name | length [mm] | partCount | comment
HSP wheel axle 1/10 | _02033 | 4 |  | M2 Flat Head | 8 | 1 | Everything between 8 and 14 mm works.
HSP Hub 1/10 | _02014 | 4 |  | M2 Brass Insert | - | 1 | Depth: 3 mm.
HSP Differential | _02051 | 1 | Use the front version. Or use the rear version with an additional longer shaft. | M3 Flat Head | 6 | 2
HSP Dogbone 77 mm | _08060 | 2 | It is sold as 77 mm, but the bore-to-bore measurement is about 72 mm. |  | 8 | 12
Tires 1/10 | - | 4 | Outer Diameter approx. 70 - 75 mm. |  | 12 | 8
Rims HEX12 1/10 | - | 4 | Optional, if you dont want to print rims. |  | 14 | 4
Shock Absorber 50mm | - | 4 | One with several different springs and oil dampening is recommended. |  | 16 | 4
Transmitter/receiver combo | - | 1 | I use Carson Reflex X1. |  | 20 | 8
ESC | - | 1 | I use Hobbywing 1060. |  | 22 | 6
Motor | - | 1 | I use Tamiya Torque Tuned. |  | 25 | 2
Motor gear | - | 1 | I use 48 dp 21 t. |  | 30 | 2
Differential gear | - | 1 | I use 48 dp 43 t. MAX DIAMATER 2 cm. |  | 45 | 4
 |  |  |  |  | 60 | 6
 |  |  |  | M3 Socket Head | 18 | 2
 |  |  |  |  | 20 | 2
 |  |  |  | M3 Ultra Thin Head | 8 | 4 | Everything between 8 and 10 mm works.
 |  |  |  | M3 Brass Insert | - | 26 | Depth: 5.7 mm .
 |  |  |  | M3 Lock Nut | - | 18
 |  |  |  | M3 Square Nut |  | 2
 |  |  |  | M3 Washer |  | 25 | "Best looking" diameter: 6.7 mm.
 |  |  |  | M4 Socket Head | 16 | 4
 |  |  |  | M4 Lock Nut | - | 8
 |  |  |  | M4 Washer | - | 4 | Diameter must be smaller than 12 mm.

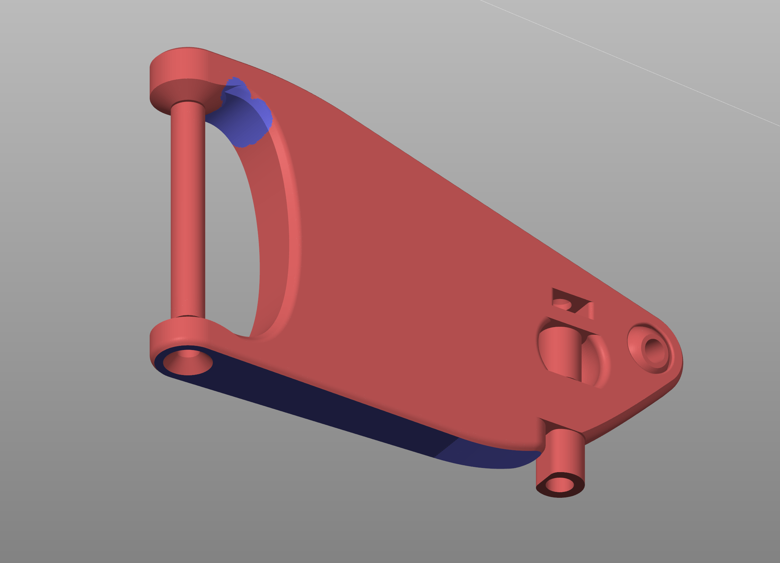
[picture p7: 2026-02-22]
printable_files(with_comments)/rc_car/FrontEnd/LowerWB/support_material/support_material.PNG

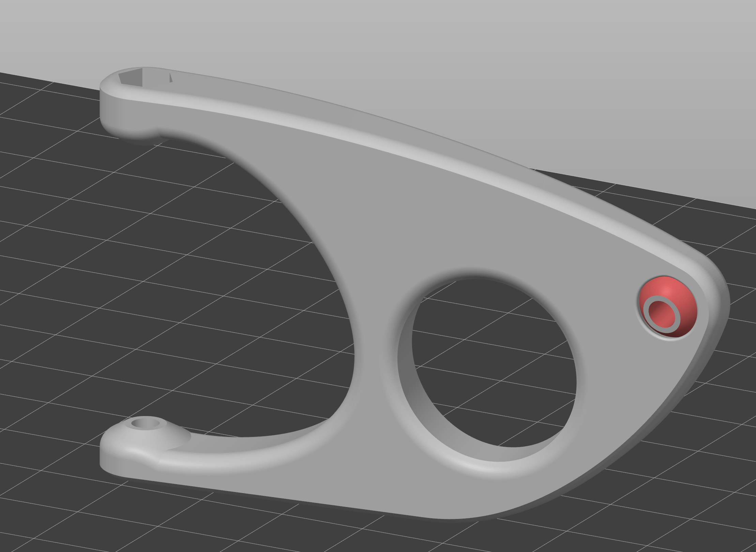
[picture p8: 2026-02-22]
printable_files(with_comments)/rc_car/FrontEnd/UpperWB/support_material/support_material1.PNG

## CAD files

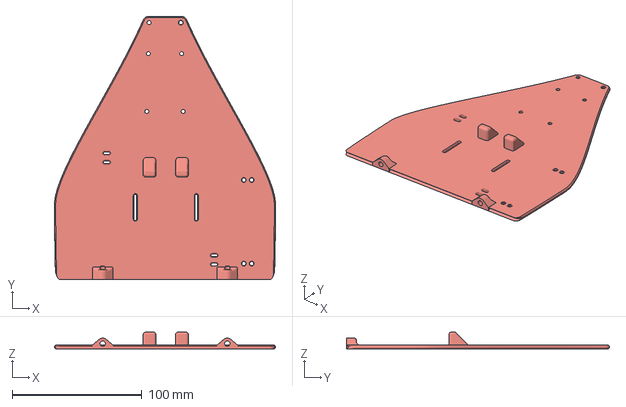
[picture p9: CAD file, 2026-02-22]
printable_files(with_comments)/rc_car/BottomPlate/FrontBottomPlate/files_to_print/FrontBottomPlate.3mf
170.2 x 202.9 x 13.0 mm

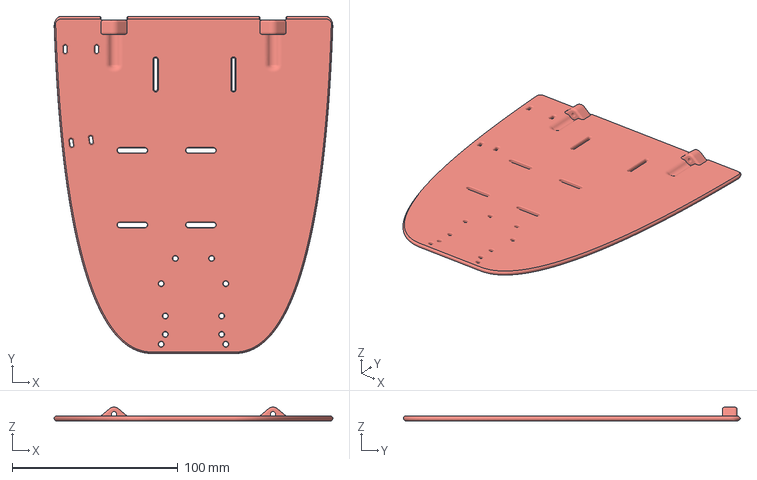
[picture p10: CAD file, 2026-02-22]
printable_files(with_comments)/rc_car/BottomPlate/RearBottomPlate/files_to_print/RearBottomPlate.3mf
168.2 x 203.5 x 8.34 mm

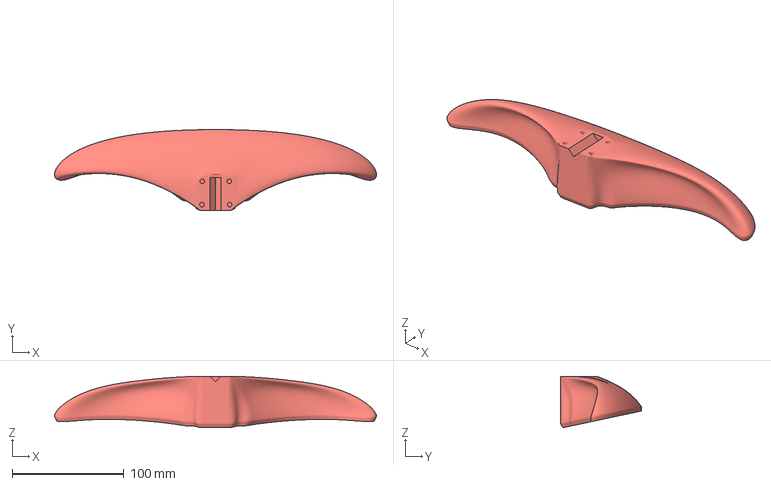
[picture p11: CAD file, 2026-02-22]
printable_files(with_comments)/rc_car/FrontBumper/files_to_print/FrontBumper.3mf
288.2 x 72.4 x 46.1 mm

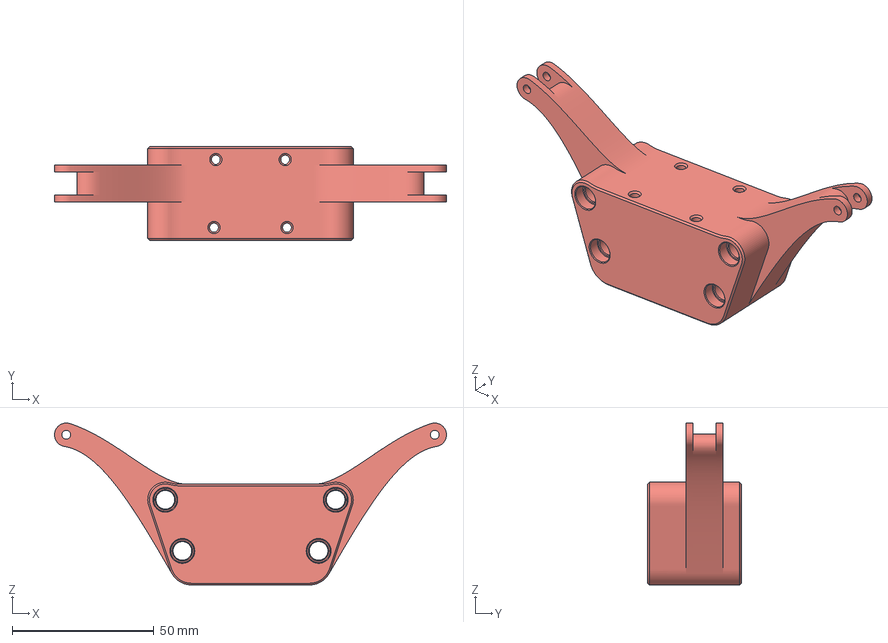
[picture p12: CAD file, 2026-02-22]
printable_files(with_comments)/rc_car/FrontEnd/FrontBase/files_to_print/FrontBase.3mf
138.1 x 33.0 x 57.0 mm

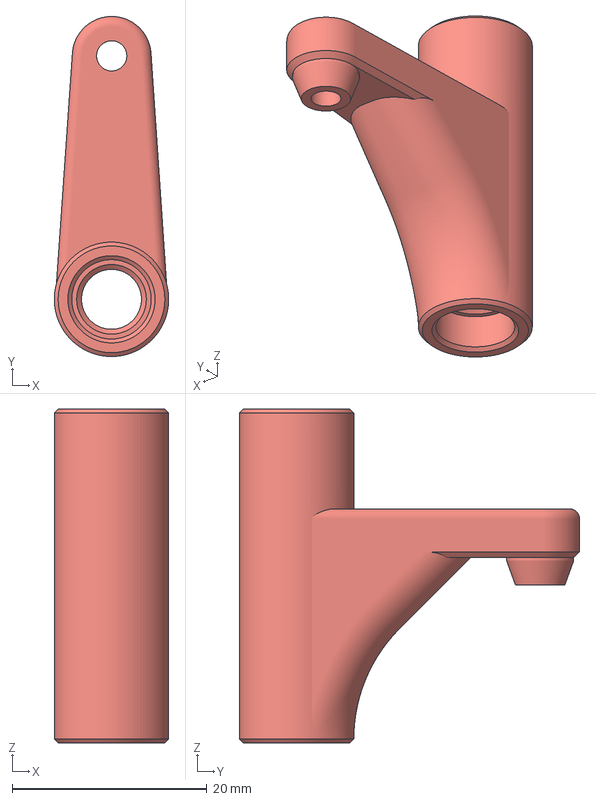
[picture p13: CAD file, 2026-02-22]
printable_files(with_comments)/rc_car/FrontEnd/LeftSteerLever/files_to_print/LeftSteerLever.3mf
11.8 x 34.9 x 34.3 mm

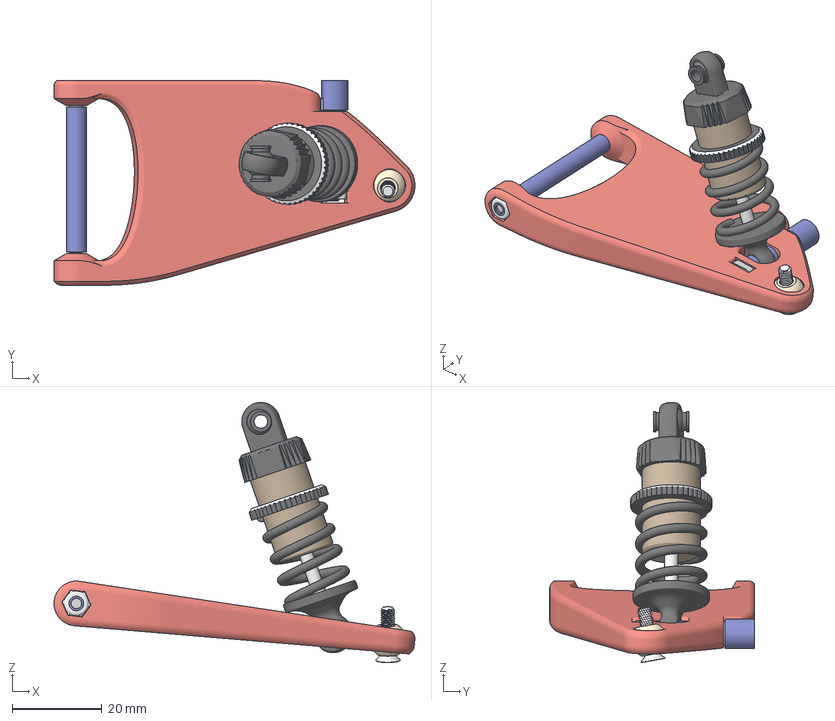
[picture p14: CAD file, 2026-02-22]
printable_files(with_comments)/rc_car/FrontEnd/LowerWB/files_to_print/LowerWB.3mf
80.6 x 45.7 x 58.1 mm
Ball1
Ball2
BallJointSphere
Körper1 x 7
Körper2 x 2
LowerWB
SupportMaterial1
SupportMaterial1.1
SupportMaterial2

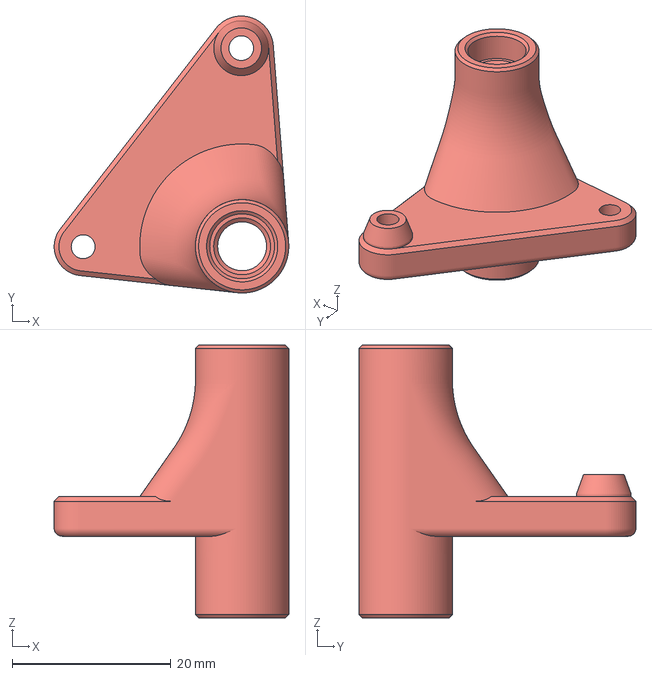
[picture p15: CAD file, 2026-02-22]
printable_files(with_comments)/rc_car/FrontEnd/RightSteerLever/files_to_print/RightSteerLever.3mf
29.5 x 34.8 x 34.3 mm

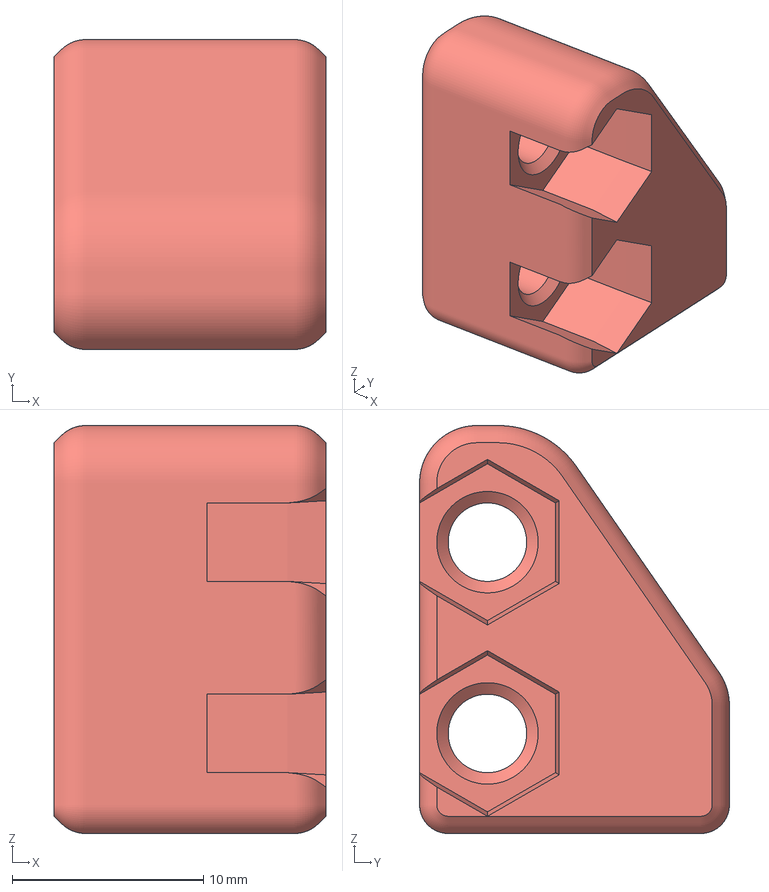
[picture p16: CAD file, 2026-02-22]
printable_files(with_comments)/rc_car/FrontEnd/ServoMountingBrackets/files_to_print/FrontMountingBracket.3mf
14.2 x 16.2 x 21.3 mm

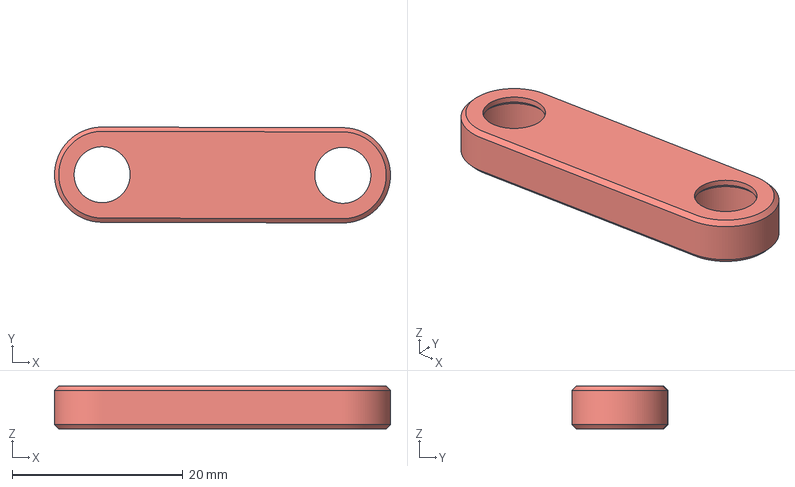
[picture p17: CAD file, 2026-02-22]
printable_files(with_comments)/rc_car/FrontEnd/SteerLeverCuppler/files_to_print/SteerLeverCuppler.3mf
39.3 x 11.2 x 5.00 mm

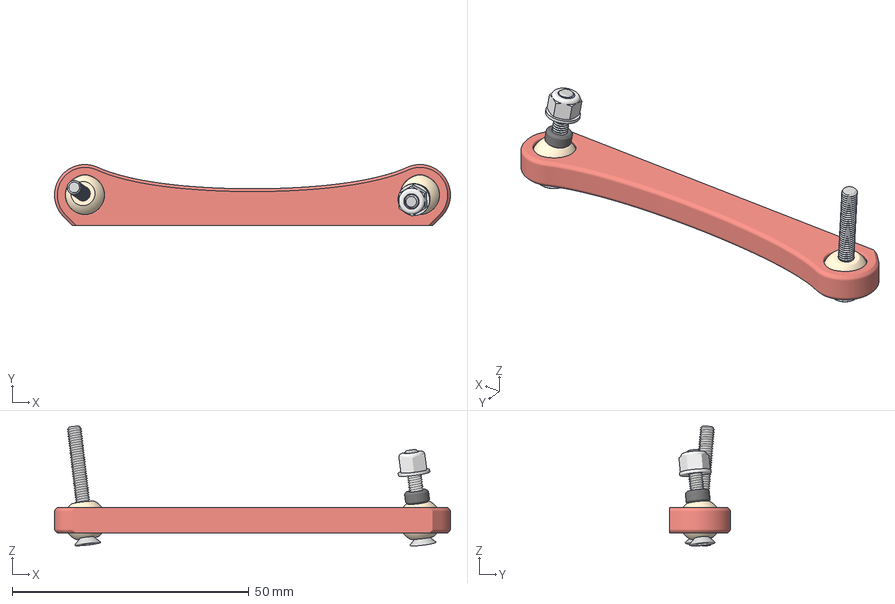
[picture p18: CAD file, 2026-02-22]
printable_files(with_comments)/rc_car/FrontEnd/SteerRod/files_to_print/SteerRod.3mf
83.6 x 12.9 x 25.3 mm
BallJointSphere (1)
BallJointSphere
Körper1 x 4
Körper2
RightSteerRod
Spacer-SteerLeverBallJointSphereHub

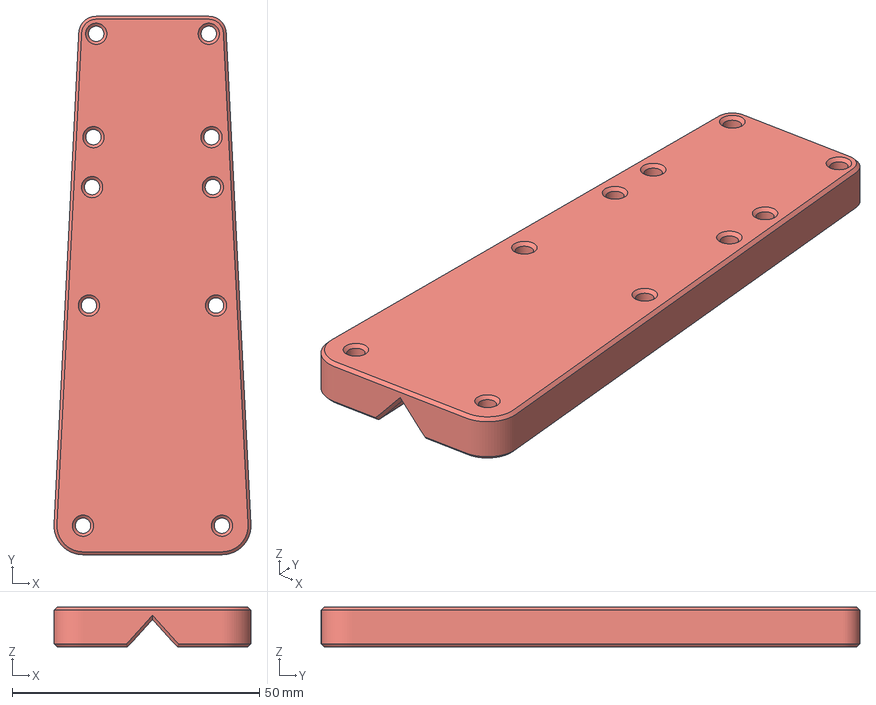
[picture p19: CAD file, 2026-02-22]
printable_files(with_comments)/rc_car/FrontEnd/TopRodConnection/files_to_print/TopTopRodConnection (1).3mf
39.8 x 108.9 x 8.00 mm

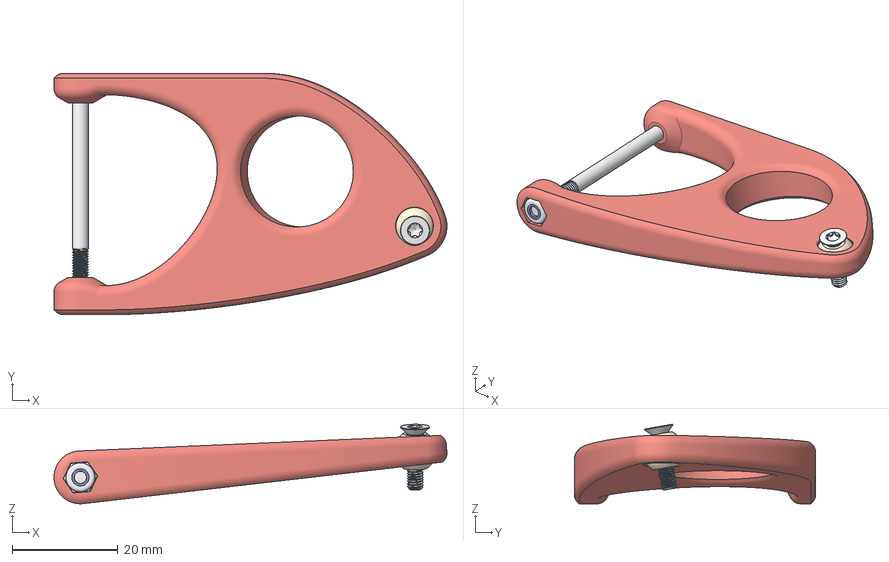
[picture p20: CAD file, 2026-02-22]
printable_files(with_comments)/rc_car/FrontEnd/UpperWB/files_to-print/RightUpperWB.3mf
74.3 x 45.6 x 15.1 mm
BallJointSphere
Körper1 x 3
Körper2
RightUpperWB

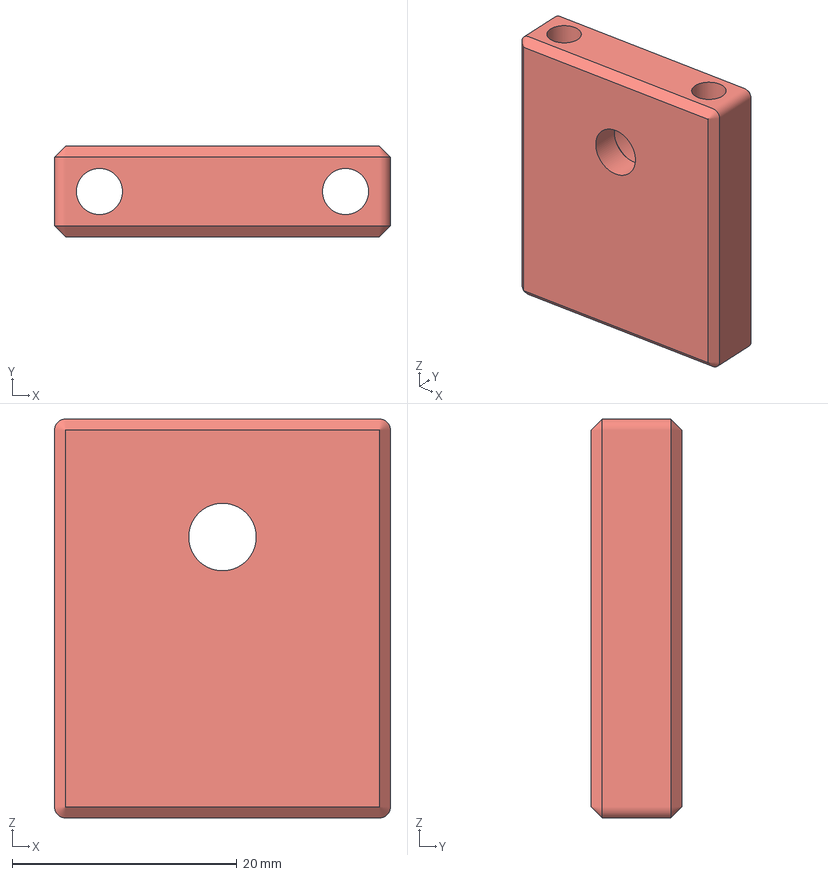
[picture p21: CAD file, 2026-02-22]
printable_files(with_comments)/rc_car/RearEnd/DifferentialShaftSupportBracket/files_to_print/DifferentialShaftSupportBracket.3mf
29.9 x 8.10 x 35.5 mm

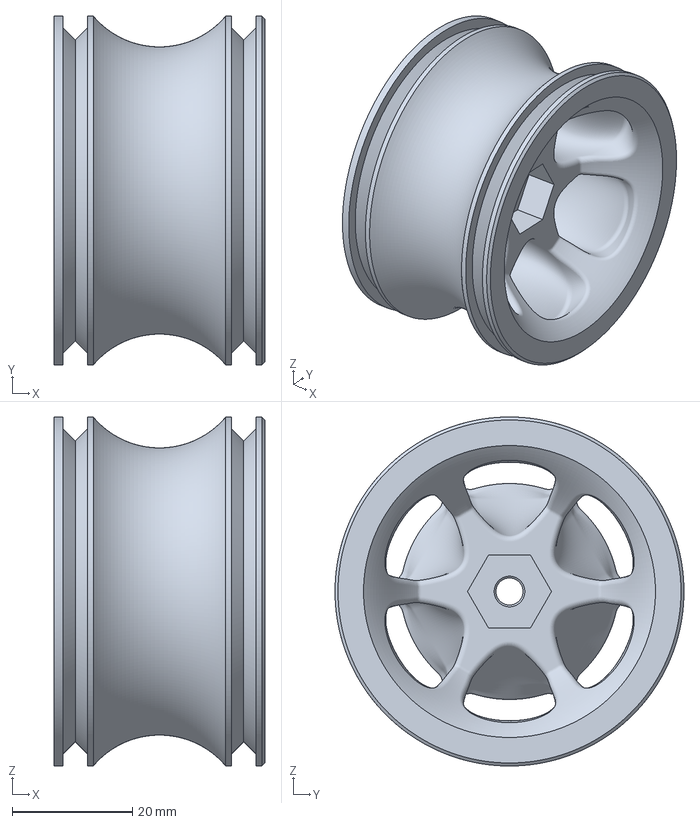
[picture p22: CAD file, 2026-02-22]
printable_files(with_comments)/rc_car/Wheels/files_to_print/Rim.3mf
35.0 x 58.0 x 58.0 mm

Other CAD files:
printable_files(with_comments)/test-prints/1_ToleranceTestObject/ToleranceTestObject.3mf
printable_files(with_comments)/rc_car/FrontEnd/FrontBase/files_to_print/BearingSpacer (FrontBase).3mf
printable_files(with_comments)/rc_car/FrontEnd/LeftSteerLever/files_to_print/BearingSpacer (LeftSteerLever).3mf
printable_files(with_comments)/rc_car/FrontEnd/RightSteerLever/files_to_print/BearingSpacer (RightSteerLever).3mf
printable_files(with_comments)/rc_car/FrontEnd/ServoMountingBrackets/files_to_print/BackMountingBracket.3mf
printable_files(with_comments)/rc_car/FrontEnd/SteerRod/files_to_print/Spacer(Hub-SteerRod).3mf
printable_files(with_comments)/rc_car/FrontEnd/TopRodConnection/files_to_print/BottomTopRodConnection (1).3mf
printable_files(with_comments)/rc_car/FrontEnd/UpperWB/files_to-print/LeftUpperWB.3mf

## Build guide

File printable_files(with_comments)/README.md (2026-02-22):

It is advised to print the "ToleranceTestObject" first. This way you don't end up wasting filament and time.

!!!!! Some folders contain READMEs with imnportant printing instructions !!!!!

--> Generally speaking, print slow with a low-medium flowrate and with very little cooling fan. This way, the printed parts will be strong because the layers adhere very well to each other.
--> Set "seam postiion" to random. This way all bearing fits are most concentric. With an alligned seam position, the concentricity of the bearing fit might be off.

I printed everything on a Sovol SV07 with a .6-nozzle at 5 mm^3/s max flow rate and 0-20 % part cooling fan.

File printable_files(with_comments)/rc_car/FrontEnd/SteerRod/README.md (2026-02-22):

Aspects to keep in mind BEFORE printing:

	--> In the Slicer, delete the part "Spacer-SteerLeverBallJointSphereHub" and all the parts named "KörperX". You only need "BallJointSphere", "BallJointSphere (1)" and "RightSteerRod".
	--> PLA works good. (PETG might has a too strong layer-adhesion for the spherical bearing, but I haven´t tried it.)
	--> NO SEAMS inside the spherical print-in-place bearing, beacause they might bond together. (Do that with "seam painting"; example pictures in folder "seam_painting".)
	--> .15 layerheigth is recommended for the spherical print-in-place bearing. (I used .30 layerheight for the object, but .15, where the spherical bearing is, by using "variable layer height".)
	--> Make sure, the part-cooling fan runs at 100 % when "BallJointSphere" and "BallJointSphere (1)" start printing. [To ensure that, I manually moved the "M106 255"-command (100 % part-cooling fan, triggered by start of bridging) up a few lines in the .gcode-file by using a text editor. This way, the fan can accelerate to the desired 100 %, before the critical printing starts. So the fan definitely is at 100 % when the bridging starts. Explained with pictures in the folder "move_fan_command".]  

Print "SteerRod" two times, no need to differentiate between "RightSteerRod" and "LeftSteerRod" since they are exayctly the same.
Print the "Spacer(Hub-SteerRod) two times.

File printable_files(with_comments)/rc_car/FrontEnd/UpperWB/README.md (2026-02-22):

Aspects to keep in mind BEFORE printing:

	--> In the Slicer, delete the all the parts named "KörperX".
	--> PLA works good. (PETG might has a too strong layer-adhesion for the spherical bearing, but I haven´t tried it.)
	--> NO SEAMS inside the spherical print-in-place bearing, beacause they might bond together. (Do that with "seam painting"; example pictures in folder "seam_painting".)
	--> .15 layerheigth is recommended for the spherical print-in-place bearing. (I used .30 layerheight for the object, but .15, where the spherical bearing is, by using a layer height modifier.)
	--> Make sure, the part-cooling fan runs at 100 % when "BallJointSphere" starts printing. [To ensure that, I manually moved the "M106 255"-command (100 % part-cooling fan, triggered by start of bridging) up a few lines in the .gcode-file by using a text editor. This way, the fan can accelerate to the desired 100 %, before the critical printing starts. So the fan definitely is at 100 % when the bridging starts. Explained with pictures in the folder "move_fan_command".]  
	--> Some extra support material is probalby needed.

Print "RightUpperWB" and "LeftUpperWB".

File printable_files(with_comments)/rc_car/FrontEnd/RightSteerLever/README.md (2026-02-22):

Aspects to keep in mind BEFORE printing:

Print the object "BearingSpacer (RightSteerLever)" and "RightSteerLever" once:

	--> The object "RightSteerLever" needs some support to be printed.

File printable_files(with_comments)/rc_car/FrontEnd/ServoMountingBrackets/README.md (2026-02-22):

Aspects to keep in mind BEFORE printing:

Print the object "BackServoMountingBracket" and "FrontServoMountingBracket" once:

	--> Use the printing orientation according to the folder "gcode_screenshots".

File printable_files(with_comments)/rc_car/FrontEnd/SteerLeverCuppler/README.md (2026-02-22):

Aspects to keep in mind BEFORE printing:

Print the object "SteerLeverCuppler" once:

	--> Use the printing orientation according to the folder "gcode_screenshots".
	--> The 693 bearings must have a very tight fit on this part. If the bearings sit too loose in the bore, they might creep out of it. You can achieve this very tight fit by overextruding.

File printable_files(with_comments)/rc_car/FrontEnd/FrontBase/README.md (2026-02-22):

Aspects to keep in mind BEFORE printing:

Print the object "FrontBase" once:

	--> For the "FrontBase", you will need support material as shown in the pictures in the folder "gcode-screenshots".
	--> Ideally, set the "seam position" to "random" and use "seam painting" to move the seams away from the bottom of the "FrontBase" (as shown in pictures in the folder "gcode-screenshots"). 

Print the object "BearingSpacer (FrontBase)" four times.

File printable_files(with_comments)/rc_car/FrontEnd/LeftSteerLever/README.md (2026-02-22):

Aspects to keep in mind BEFORE printing:

Print the object "BearingSpacer (LeftSteerLever)" and "LeftSteerLever" once:

	--> The object "LeftSteerLever" needs some support to be printed.

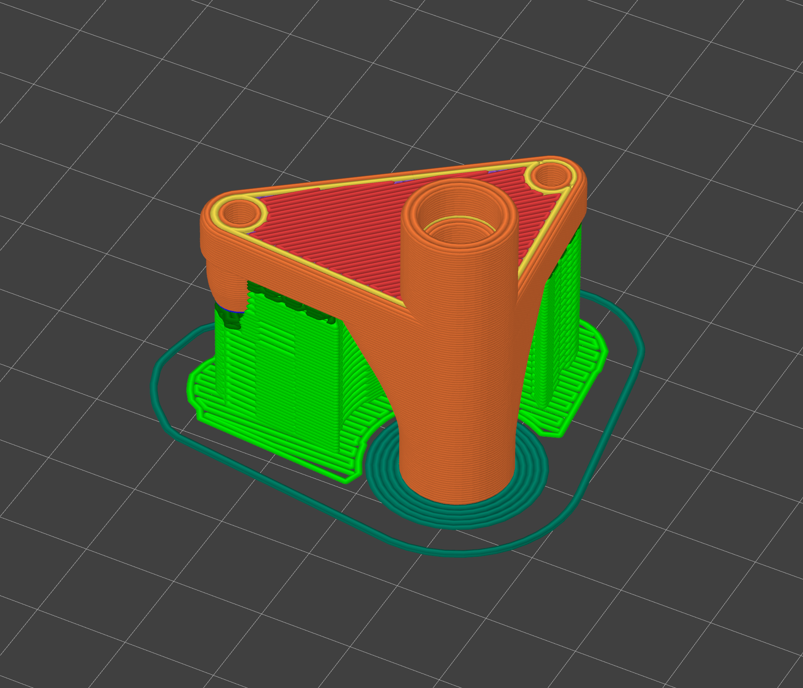
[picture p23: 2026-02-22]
printable_files(with_comments)/rc_car/FrontEnd/RightSteerLever/gcode_screenshots/RightSteerLever2.PNG

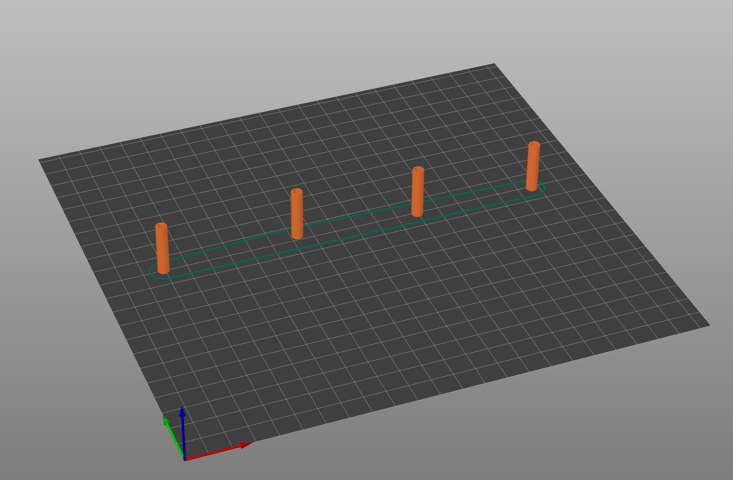
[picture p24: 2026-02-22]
printable_files(with_comments)/rc_car/FrontEnd/FrontBase/gcode_screenshots/BearingSpacer (FrontBase).PNG

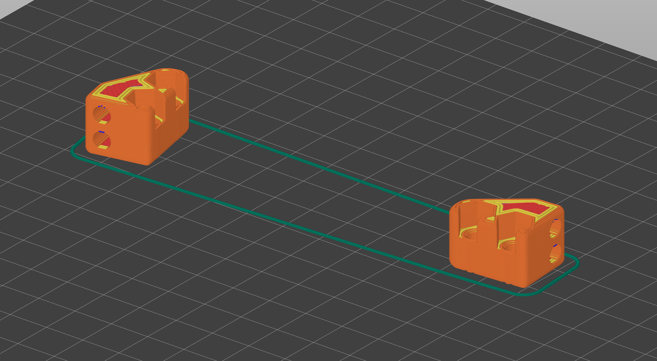
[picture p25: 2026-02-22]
printable_files(with_comments)/rc_car/FrontEnd/ServoMountingBrackets/gcode_screenshots/ServoMountingBrackets.PNG

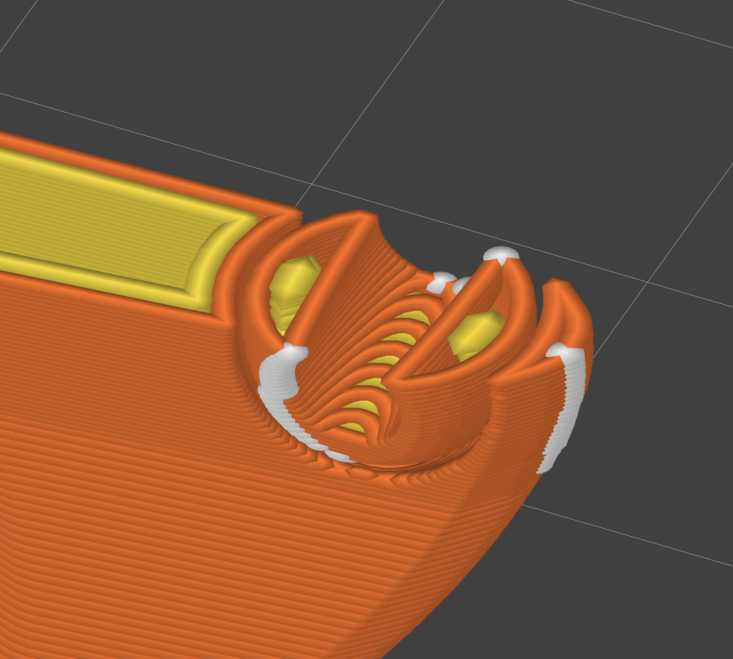
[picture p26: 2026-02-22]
printable_files(with_comments)/rc_car/FrontEnd/UpperWB/seam_painting/Seam-outside-spherical-bearing_(GOOD).PNG

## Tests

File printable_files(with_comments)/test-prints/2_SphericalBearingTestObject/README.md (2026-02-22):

!!!!! Print with similar settings to the "real print" !!!!!

The second and final test print is a print-in-place spherical bearing, used in the front suspension.

YOU HAVE TO use the "seam painting" feature in your slicer according to the two pictures in this folder! 
Otherwise the inner sphere and the outer ring probably bond together.

After printing, you should be able to break the inner sphere loose from the outer ring.
By rotating the spherical bearing a few times you smooth the surfaceses and it should moce freely.
Apply some grease now.

If it is too tight or loose, adjust the parameters as explained in README#1, edit the gcode fan command and print the test again.

My own optimal parameters are:

	PrintInPlaceBallJointHoleDia = 0.33 cm
	PrintInPlaceBallJointTolerance = 0.022 cm

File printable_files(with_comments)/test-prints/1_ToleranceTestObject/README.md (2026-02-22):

!!!!! Print with similar settings to the "real print" !!!!!

The first test print is an object to determine wether my parameters fit yours or if they need to be adjusted. 

Print the ToleranceTestObject and check if your hardware fits in the holes.
In the image "xxx" you can see where to put which nut/bolt/bearing/insert.

If some features in this print are too wide or narrow, you can adjust the according parameters in Fusion360 and export the ToleranceTestObject again.

Only adjust the parameters mentioned in the README. Adjusting other parameters might cause conflicts in Fusion360s timeline.
Here are my personal parameter values and the ranges in which each parameter can can safely be modified:

	M2InsertDia = 0.3 cm	M2 threaded brass insert diameter (tested in Fusion360 from 0.28 cm to 0.35 cm)

	M3HoleDia = 0.31 cm	M3 hole diameter (tested in Fusion360 from 0.29 cm to 0.36 cm)
	M3InsertDia = 0.41 cm	M3 threaded brass insert diameter (tested in Fusion360 from 0.29 cm to 0.36 cm)
	M3NutS = 0.565 cm	M3 nut measured side to side (tested in Fusion360 from 0.54 cm to 0.61 cm)
	M3SquareNutS = 0.57 cm	M3 square-nut measured side to side(tested in Fusion360 from 0.54 cm to 0.61 cm)

	M4HoleDia = 0.41 cm	M4 hole diameter (tested in Fusion360 from 0.39 cm to 0.46 cm)
	M4NutS = 0.71 mm	M4 nut, measured side to side (tested in Fusion360 from 0.69 cm to 0.76 cm)

	Bearing963Dia = 0.81 cm	(963 bearing diameter) (tested in Fusion360 from 0.78 cm to 0.86 cm)
	BearingMR105Dia = 1.0125 cm (MR105 bearing diameter) (tested in Fusion360 from 0.98 cm to 1.06 cm)
